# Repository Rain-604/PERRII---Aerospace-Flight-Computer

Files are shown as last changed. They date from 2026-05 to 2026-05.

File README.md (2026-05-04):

# PERRII – Aerospace Flight Computer

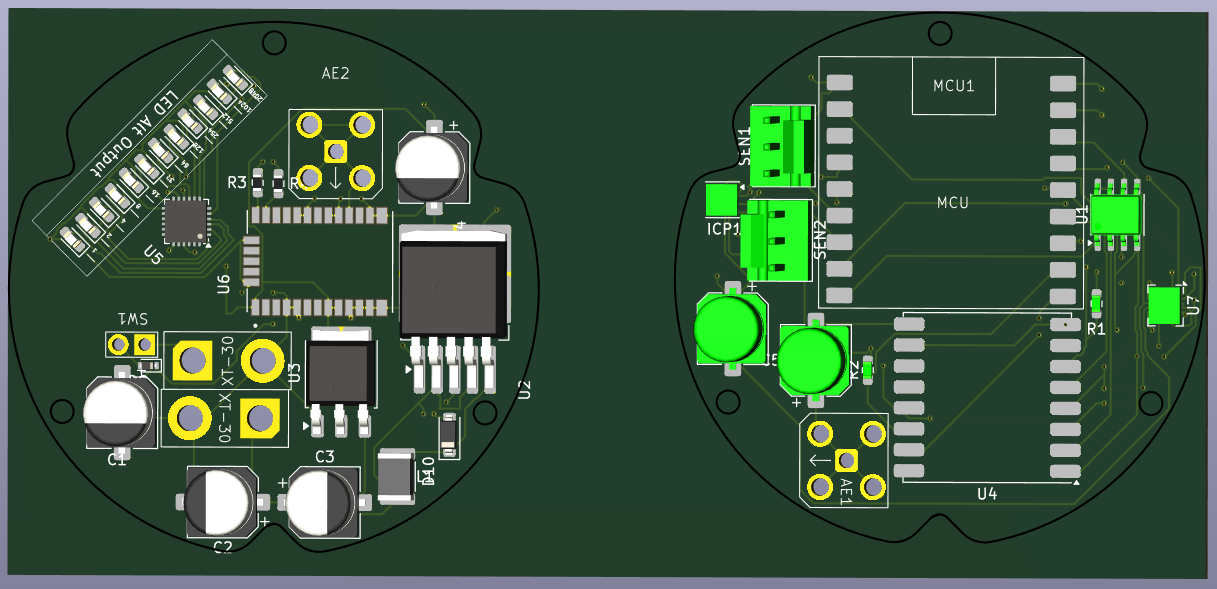
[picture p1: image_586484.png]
3D Render


## Project Overview
PERRII is a modular aerospace flight computer designed for environmental sensing and long-range data telemetry. The system is built around the ESP32-S3 Zero microcontroller and is designed to function as a scientific payload for high-altitude ballooning or atmospheric research. It integrates precision GNSS positioning, environmental gas sensing (Methane and Ammonia), and a robust power regulation system.

## My Contribution: LoRa Communication Subsystem
As the lead for the communication system, I was responsible for the hardware integration and signal integrity of the long-range telemetry link.

### Key Technical Implementations:
* **RFM98W Integration**: Integrated the RFM98W-433S2 LoRa transceiver to provide a robust, low-power, long-distance communication link between the flight computer and the ground station.
* **RF Hardware Design**: Designed the antenna interface for the AE1 Antenna, including a 100pF decoupling capacitor (C5) to ensure signal stability.
* **SPI Interface Management**: Configured the SPI bus (MOSI, MISO, SCK, NSS) to interface the RF module with the ESP32-S3, managing critical interrupt lines (DIO0-DIO5) for real-time packet handling.
* **RF Layout Optimization**: Optimized the trace routing between the RF transceiver and the antenna connector to maintain signal integrity in a compact, circular PCB form factor.

## System Architecture
While my primary focus was the communication link, I worked closely with the team to integrate the following subsystems:

### 1. Navigation & Sensing
* **GNSS Positioning**: Integration of a u-blox CAM-M8C-D GPS module for real-time tracking.
* **Environmental Monitoring**: Active monitoring of atmospheric data via SEN1 (Methane) and SEN2 (Ammonia) gas sensors.
* **Visual Telemetry**: A dedicated LED altitude output array driven by the AW9523B LED driver.

### 2. Power Management
* **Dual-Stage Regulation**: The system utilizes a high-efficiency LM2596S-5 switching buck converter for the primary 5V rail and an LM1117DT-3.3 LDO for the sensitive logic and RF rails.
* **Robust Input**: Featuring XT-30 battery connectors and reverse polarity protection via a D10 Schottky diode.

## Design Files
### 1. Schematic Design
The schematic follows a modular design separated into Power, TX, Sensor, and GPS blocks.

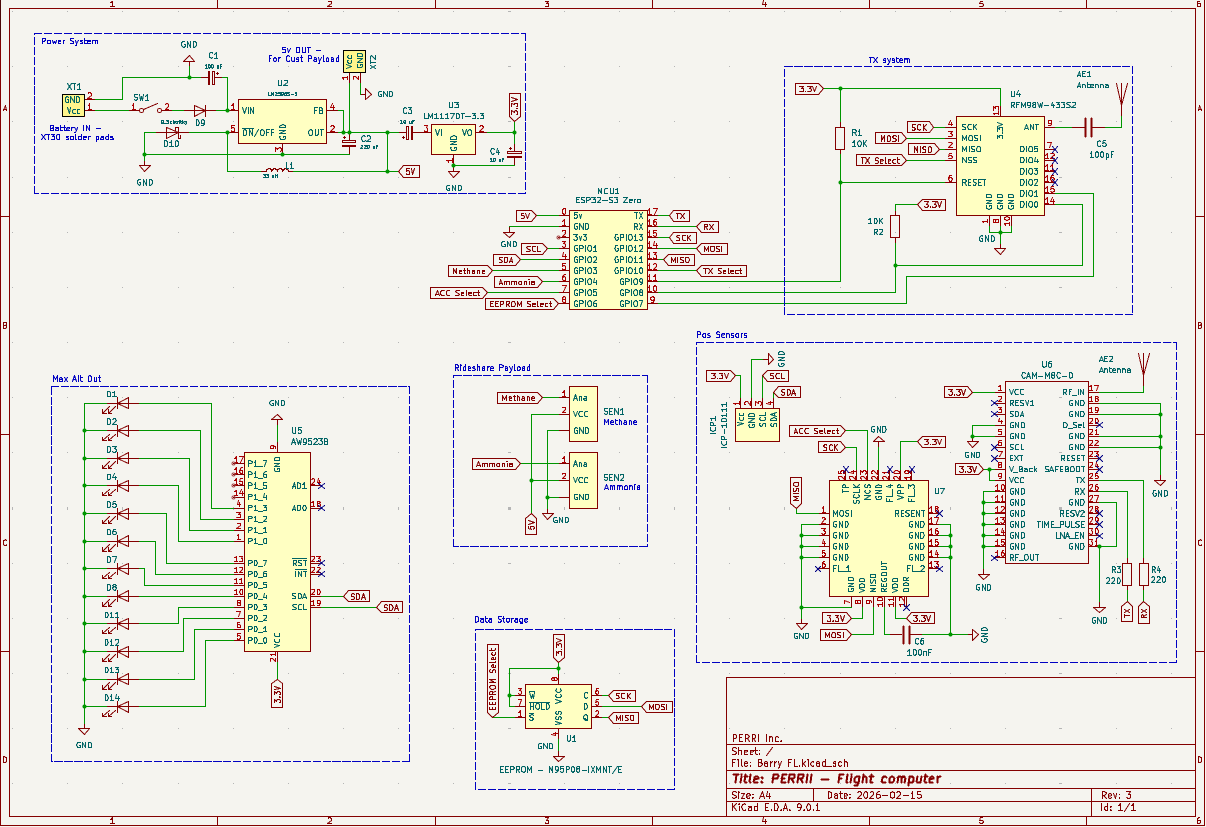
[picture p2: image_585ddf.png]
Schematic View


### 2. PCB Layout
A circular 2-layer board designed for cylindrical aerospace housing.

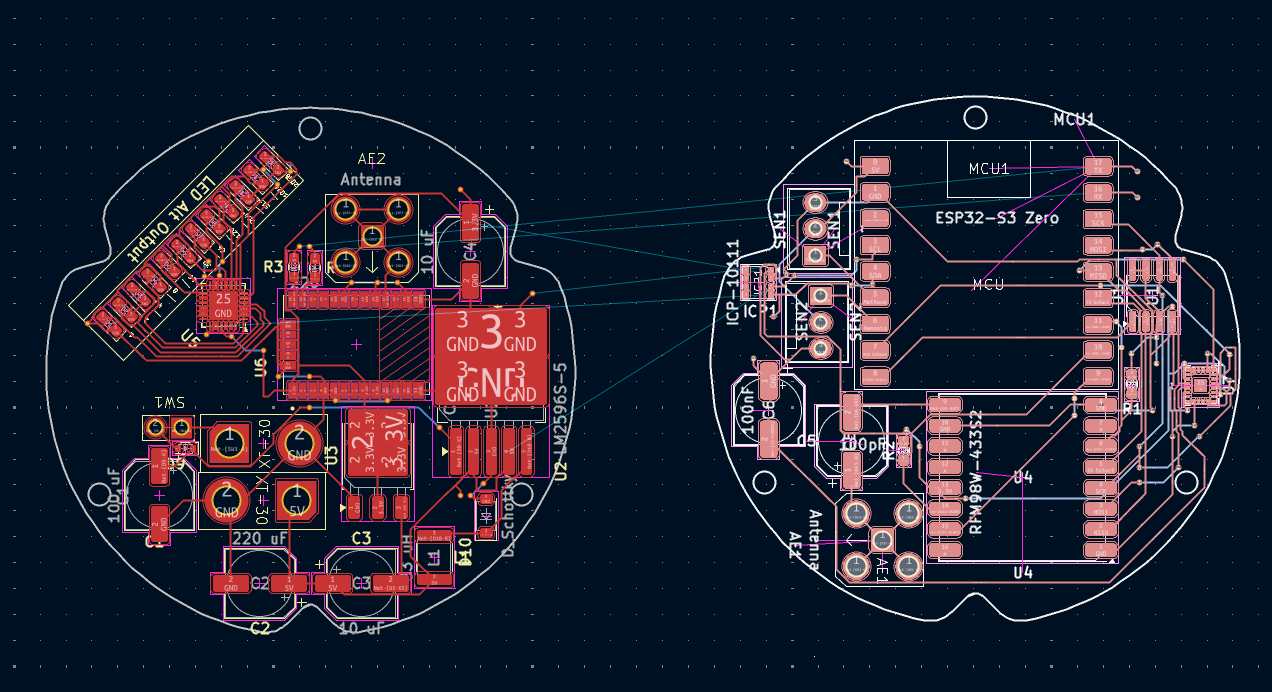
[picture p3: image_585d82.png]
PCB Layout


## Team & Credits
* **Lok Yu Lui (Rain)**: Hardware Engineer – LoRa Communication Subsystem.
* **PERRII Team**: Collaborative effort for MCU integration, Power Systems, and Sensor Payloads.

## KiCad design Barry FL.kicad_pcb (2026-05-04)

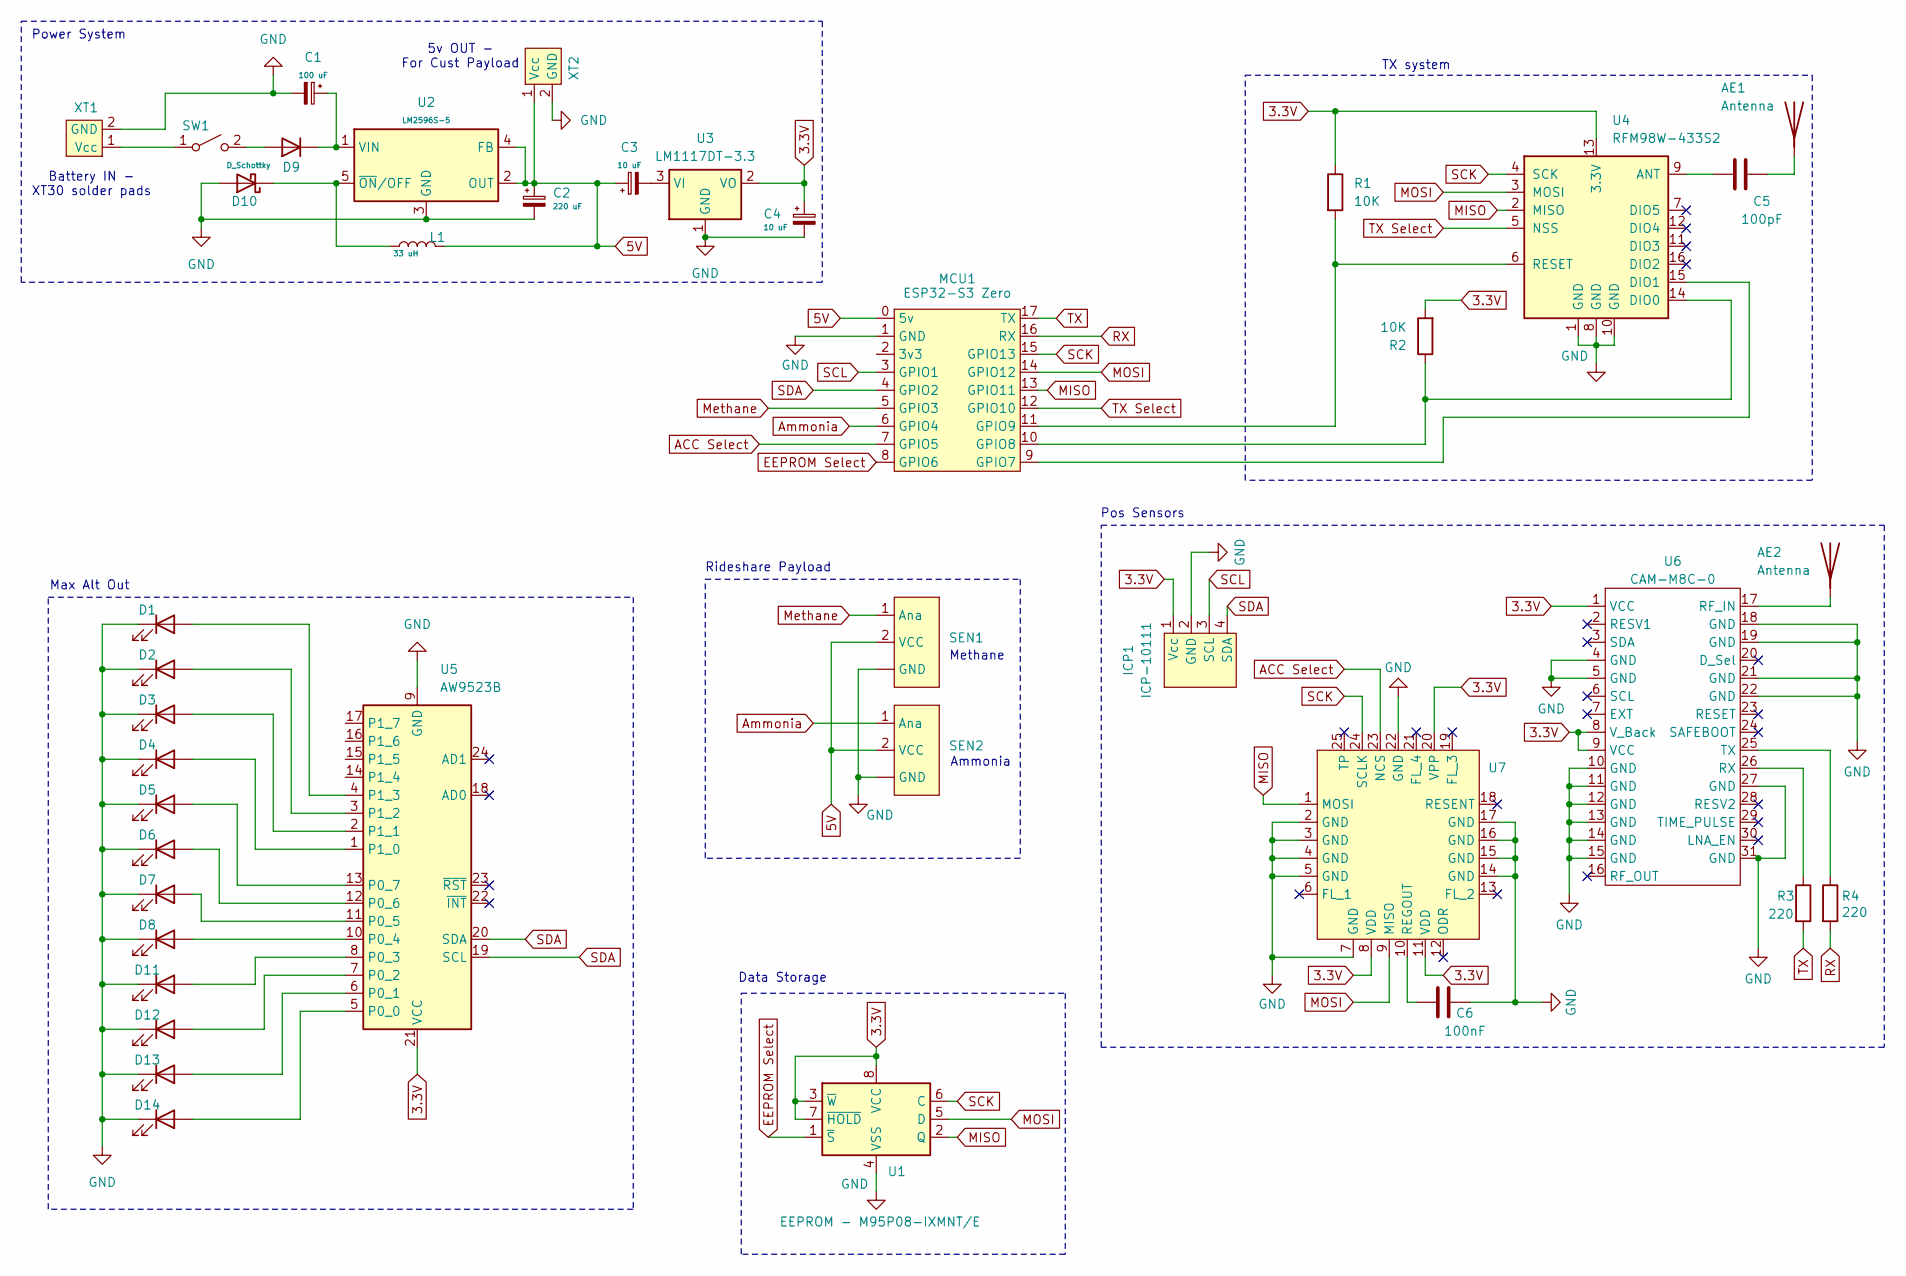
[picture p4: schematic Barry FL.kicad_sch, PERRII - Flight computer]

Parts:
AE1: Antenna; 132203
AE2: Antenna
C1: 100 uF
C2: 220 uF
C3, C4: 10 uF
C5: 100pF
C6: 100nF
D1, D2, D3, D4, D5, D6, D7, D8, D11, D12, D13, D14: LED; LED_0603_1608Metric_Pad1.05x0.95mm_HandSolder
D9: 1N4148WT; D_SOD-523
D10: D_Schottky
ICP1: ICP-10111
L1: 33 uH
MCU1: ESP32-S3 Zero; ESP32-S3 Zero Mini Development Board
R1, R2: 10K; R_0603_1608Metric_Pad0.98x0.95mm_HandSolder
R3, R4: 220; R_0603_1608Metric_Pad0.98x0.95mm_HandSolder
SEN1, SEN2: SEN Footprint
SW1: Jumper
U1: EEPROM - M95P08-IXMNT/E; SOIC-8_3.9x4.9mm_P1.27mm
U2: LM2596S-5; TO-263-5_TabPin3
U3: LM1117DT-3.3; TO-252-3_TabPin2
U4: RFM98W-433S2
U5: AW9523B; QFN-24-1EP_4x4mm_P0.5mm_EP2.7x2.7mm
U6: CAM-M8C-0
U7: (no value)
XT1, XT2: XT_30

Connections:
3.3V: C4.1, ICP1.1 (Vcc), R1.1, R2.2, U1.3 (~W), U1.7 (~HOLD), U1.8 (VCC), U3.2 (VO), U4.13 (3.3V), U5.21 (VCC), U6.1 (VCC), U6.8 (V_Back), U6.9 (VCC), U7.8 (VDD), U7.11 (VDD), U7.20 (VPP)
5V: C2.1, C3.1, L1.2, MCU1.0 (5v), SEN1.2 (VCC), SEN2.2 (VCC), U2.2 (OUT), U2.4 (FB), XT2.1 (Vcc)
ACC Select: MCU1.7 (GPIO5), U7.23 (NCS)
Ammonia: MCU1.6 (GPIO4), SEN2.1 (Ana)
EEPROM Select: MCU1.8 (GPIO6), U1.1 (~S)
GND: C1.2, C2.2, C4.2, C6.1, D1.1 (K), D2.1 (K), D3.1 (K), D4.1 (K), D5.1 (K), D6.1 (K), D7.1 (K), D8.1 (K), D10.2 (A), D11.1 (K), D12.1 (K), D13.1 (K), D14.1 (K), ICP1.2 (GND), MCU1.1 (GND), SEN1. (GND), SEN1.3 (GND), SEN2. (GND), SEN2.3 (GND), U1.4 (VSS), U2.3 (GND), U3.1 (GND), U4.1 (GND), U4.8 (GND), U4.10 (GND), U5.9 (GND), U5.25 (GND), U6.4 (GND), U6.5 (GND), U6.10 (GND), U6.11 (GND), U6.12 (GND), U6.13 (GND), U6.14 (GND), U6.15 (GND), U6.18 (GND), U6.19 (GND), U6.21 (GND), U6.22 (GND), U6.27 (GND), U6.31 (GND), U7.2 (GND), U7.3 (GND), U7.4 (GND), U7.5 (GND), U7.7 (GND), U7.14 (GND), U7.15 (GND), U7.16 (GND), U7.17 (GND), U7.22 (GND), XT1.2 (GND), XT2.2 (GND)
MISO: MCU1.13 (GPIO11), U1.2 (Q), U4.2 (MISO), U7.1 (MOSI)
MOSI: MCU1.14 (GPIO12), U1.5 (D), U4.3 (MOSI), U7.9 (MISO)
Methane: MCU1.5 (GPIO3), SEN1.1 (Ana)
unnamed: AE1.1 (A), C5.1
unnamed: AE2.1 (A), U6.17 (RF_IN)
unnamed: D1.2 (A), U5.4 (P1_3)
unnamed: D2.2 (A), U5.3 (P1_2)
unnamed: D3.2 (A), U5.2 (P1_1)
unnamed: D4.2 (A), U5.1 (P1_0)
unnamed: D5.2 (A), U5.13 (P0_7)
unnamed: D6.2 (A), U5.12 (P0_6)
unnamed: D7.2 (A), U5.11 (P0_5)
unnamed: D8.2 (A), U5.10 (P0_4)
unnamed: D9.2 (A), SW1.2 (B)
unnamed: C1.1, D9.1 (K), U2.1 (VIN)
unnamed: D10.1 (K), L1.1, U2.5 (~ON/OFF)
unnamed: D11.2 (A), U5.8 (P0_3)
unnamed: D12.2 (A), U5.7 (P0_2)
unnamed: D13.2 (A), U5.6 (P0_1)
unnamed: D14.2 (A), U5.5 (P0_0)
unnamed: MCU1.9 (GPIO7), U4.15 (DIO1)
unnamed: MCU1.10 (GPIO8), R2.1, U4.14 (DIO0)
unnamed: MCU1.11 (GPIO9), R1.2, U4.6 (RESET)
unnamed: SW1.1 (A), XT1.1 (Vcc)
unnamed: C3.2, U3.3 (VI)
unnamed: C5.2, U4.9 (ANT)
unnamed: R3.1, U6.26 (RX)
unnamed: R4.1, U6.25 (TX)
unnamed: C6.2, U7.10 (REGOUT)
RX: MCU1.16 (RX), R4.2
SCK: MCU1.15 (GPIO13), U1.6 (C), U4.4 (SCK), U7.24 (SCLK)
SCL: ICP1.3 (SCL), MCU1.3 (GPIO1)
SDA: ICP1.4 (SDA), MCU1.4 (GPIO2), U5.19 (SCL), U5.20 (SDA)
TX: MCU1.17 (TX), R3.2
TX Select: MCU1.12 (GPIO10), U4.5 (NSS)

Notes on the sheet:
Data Storage
Power System
Battery IN - XT30 solder pads
Pos Sensors
Ammonia
Max Alt Out
TX system
Methane
Rideshare Payload
5v OUT - For Cust Payload

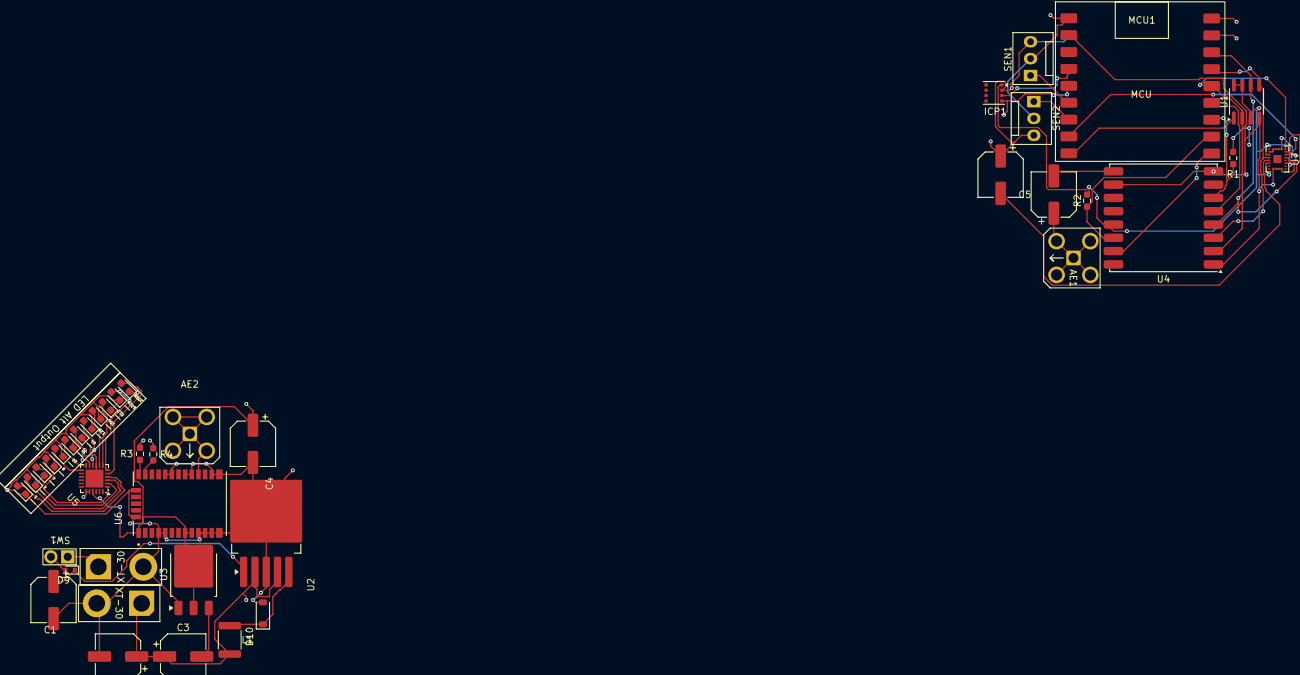
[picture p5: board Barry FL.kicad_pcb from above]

Board: 2 copper layers, 41 parts (0 on the bottom side), 41 nets.
